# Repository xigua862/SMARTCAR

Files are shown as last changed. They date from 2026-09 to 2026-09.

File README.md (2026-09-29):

# SMARTCAR · 智能循迹小车

本分支为 **FW:0929-R1**，基于 `fw-0926-G40` 修复葫芦圈换向相关控制问题。参见[修改与试车说明](README-0929-R1.md)；可直接下载[已编译 HEX](firmware/0929-R1/test16.hex)。编译和软件回归通过，尚未实车验证；本版关闭固定里程强制右转，末端出口需另行标定。

西南石油大学校赛智能车（2026 年 10 月）—— 循迹 + 差速竞速车。
**STM32F103C8T6 + HAL 库 + Keil MDK 工程**；赛道为黑底 25mm 白线，含直角弯 / 十字 / Ω 回头弯 / 相切圆环。

---

## 硬件

| 部分 | 说明 |
|---|---|
| 主控 | STM32F103C8T6 核心板（插在自制 PCB 上） |
| 驱动 | TB6612 ×1 → 2× JGA25-370 减速电机（620rpm，差速转向） |
| 循迹 | 8 路灰度/红外模块（数字量，装在车头前伸的**可调扩展板**上，前瞻 124mm） |
| 测速 | 编码器正交解码（左 TIM3 = PA6/PA7，右 TIM4 = PB6/PB7） |
| 姿态 | MPU6050（I2C2 = PB10/PB11） |
| 底盘 | 三点式：后两轮驱动 + 前球脚轮；3D 打印底板（149.84 × 122.69 × 2.5mm） |
| 人机 | LED×3（PC13/PB14/PB15，**高电平点亮**）+ 启动键（PB9）+ 蜂鸣器（PA11，当前硬件故障） |

## 目录

```
Core/App/             ← 我们自己写的分层框架（唯一需要改的地方）
  app_config.h        ★★ 调参入口：参数 / 功能开关 / 引脚表 / 版本号
  app.c/.h            顶层调度（10ms 控制节拍 + 10ms 人机节拍 + 遥测节拍）
  telemetry.c/.h      串口遥测 + 在线调参（寄存器级中断，防 HAL 卡死）
  drivers/            motor / line_sensor / speed / encoder / led / buzzer / key / imu / odom(里程计)
  control/            pid / filter / line_follow（PD + 速度自适应 + 丢线 + 十字 + 葫芦出圈）
  fsm/car_fsm.c       状态机 IDLE→读秒→RUN→STOPPED/EMERGENCY
Core/Src  Core/Inc    CubeMX 生成的（main/gpio/tim/usart/it/msp/freertos）+ 手写 i2c.c（I2C2）
                      + FreeRTOSConfig.h（RTOS 配置）
Drivers/              ST 官方 HAL + CMSIS
Middlewares/          FreeRTOS + CMSIS-RTOS2（2026-09-23 队友引入）
MDK-ARM/              Keil 工程 test16.uvprojx
文档/                  设计文档 / 比赛规则 / 调研记录 / 代码交接说明 / **实车复盘**
机械结构/               SolidWorks 模型 + STL（底板、扩展板）
硬件设计/               PCB 工程包 + BOM
脚本/                  tune.ps1（串口调参辅助）
```

## 编译 & 烧录

1. Keil uVision5 打开 `MDK-ARM/test16.uvprojx` → `F7` 编译 → `F8` 下载
2. 命令行编译：`UV4.exe -b "MDK-ARM\test16.uvprojx" -o "MDK-ARM\build.log"`
3. 或用 OpenOCD（ST-Link，SWD：PA13/PA14）：
   ```
   openocd -f interface/stlink.cfg -c "transport select swd" -f target/stm32f1x.cfg \
           -c "adapter speed 500" -c "program MDK-ARM/test16/test16.hex verify reset exit"
   ```

## 串口命令（115200，每条必须以 `\r\n` 结尾）

| 命令 | 作用 |
|---|---|
| `P 3.0` / `D 0.5` | 设 KP / KD |
| `S 70` | 设**直道**速度（弯道自动 ×0.7） |
| `T 1 40` / `T 2 40` | 单电机测试（正数 = 前进）；`T 0 0` 停 |
| `M 40 40` | 直接给左右轮 PWM（测试模式） |
| `L 0~7` | 直接点灯（bit0=LED1） |
| `B [ms]` | 蜂鸣器响 |
| `R` | 串口启动（= 按启动键：3 秒读秒 → 跑） |
| `V` | 打印版本横幅 |
| `H` | 诊断：8 路位图 + 按键 + 编码器 + IMU（`WHO=` 应为 68） |
| `O` | 读里程：`ODOM NOW: OD=xxxxmm PATH=yyyymm L=.. R=..`（**手推标定用**） |
| `Z` | 里程清零：`OK ODOM RESET`（不用断电就能反复测） |
| `X` | **急停**（连发两个 `XX` 才生效，防噪声误触发） |

**遥测行**（待机 500ms / 运行中 50ms 一行；字段很多，常用的加粗）：
```
FW:0923-5400 IR:10110000 RPM1=210 RPM2=205 KP=3.0 SP=52 ST=2 DT=10 OD=1234 PATH=1250
ODE=0 OS=0 GZ=0 GW=0 SB=0 G7=3 GX=0 GR=0 CX=4 BR=1 GE=0 GD=0 IG=0 EH=1
```
| 字段 | 含义 |
|---|---|
| **`ST=`** | 0 待机 / 1 读秒 / 2 运行 / 3 到站 / 4 急停 |
| **`IR=`** | 8 路位图，**第 1 个字符 = 最左那一路**（权重 -7…+7） |
| `RPM1/2` | 左右轮实测转速（编码器） |
| **`DT=`** | **实测控制周期**（应稳定在 10；明显 >10 = 主循环被拖慢） |
| **`OD=` / `PATH=`** | 里程：净位移 / 走过总路程（mm） |
| **`ODE=`** | 从"进葫芦圈那一刻"起算的位移（mm）—— 出圈里程判据就看它 |
| `OS=` | 本窗口内"同一拍多次子采样位图不一致"的拍数（>0 = 过采样在起作用） |
| `GZ=` | MPU6050 偏航率（°/s） |
| `GW=` | 葫芦相切点计数（`USE_GOURD_SM`，现在主要当诊断用） |
| `SB=` | 直线提速生效中 |
| `G7/GX/GR` | 最右一路触发计数 / 已触发过出圈标志 / 硬转剩余拍数（`USE_G7_TURN=0` 时后两个恒 0） |
| **`CX=` / `BR=`** | 判成十字的次数 / "只贴一端→拒绝当十字"的次数 |
| `GE/GD/IG/EH` | 出圈状态机：进圈印记 / 印记倒计时 / 是否在圈内 / 边缘保持生效 |

## 调参入口（只在 `Core/App/app_config.h`）

> ⚠️ 这个文件现在有 780+ 行、分节带注释，**改之前先读该节顶部的说明**——里面写了每个数的来历
> （哪个是实测的、哪个是推算的、改电压要重算哪些）。以下只列分类，不重复数值。

- 开关：`USE_ENCODER` / `USE_IMU` / `USE_SPEED_LOOP` / `USE_ADAPTIVE_SPEED` / `USE_D_FILTER` / `USE_STRAIGHT_BOOST` / `AUTO_START_ENABLE`
- 十字：`CROSS_ACTIVE_MIN` / `CROSS_CONFIRM_CNT` / `CROSS_MAX_FRAMES` / `CROSS_NEED_BOTH_ENDS` / `USE_CROSS_BUDGET` + `CROSS_BUDGET_MAX` / `CROSS_REARM_FRAMES`
- **葫芦出圈**：`USE_GOURD_EXIT`（总开关）/ `USE_GOURD_EXIT_ODOM` + `GOURD_EXIT_ODOM_MM` + `GOURD_EXIT_ODOM_FROM_START`（里程判据）/ `GOURD_EXIT_USE_YAW`（偏航角闭环）/ `GOURD_EXIT_TURN_FRAMES`（拍数保险）/ `USE_GOURD_IG_GYRO`（进圈判据）
- 旧的"最右一路计数硬转"：`USE_G7_COUNT`（计数，诊断用，**保持开**）/ `USE_G7_TURN`（**当前 0 = 关**，见下方复盘）
- 红外过采样：`LINE_OS_ENABLE` / `LINE_OS_SAMPLES` / `LINE_OS_SPACING_US` / `LINE_OS_VOTE_MAJORITY`
- 边缘保持：`USE_EDGE_HOLD`；提速：`STRAIGHT_BOOST_*`
- 循迹：`KP` / `KD` / `SPEED_STRAIGHT` / `SPEED_CURVE` / `CURVE_ABS_ERR_THRESH`
- 丢线：`LOST_SPIN_DELAY` / `LOST_SPIN_SPEED` / `LOST_MAX_CYCLES`
- 里程计：`ODOM_UM_PER_COUNT`（um/计数）、`ODOM_SIGN_L/R`
- 速度闭环：`SPD_PID_KP/KI/KD/IMAX`、`RPM_PER_PWM_X100`（**改电池电压要按比例改它**）
- 极性：`LINE_ACTIVE_LEVEL`（本车 8 路模块 = **白线输出高** → `GPIO_PIN_SET`）
- 电机方向：`MOTOR_LEFT_INVERT` / `MOTOR_RIGHT_INVERT`
- 版本：`FW_TAG`（改完代码更新，**取真实时间** → 串口每行都带，一眼确认烧没烧）

## ⚠️ 踩过的坑（改代码前先看）

1. **CubeMX 重新生成后必查三处**：`usart.c` 的 USER CODE 区要保留 WordLength/StopBits/Parity/**Mode** 四行（6.17 生成时会吞掉 → 串口收发全废）；`main.c` 的 `#include "app.h"` 必须在 USER CODE 区；`.ioc` 里编码器枚举要写 `TIM_ENCODERMODE_TI12`
2. **PB10/PB11 上是 I2C2，不是 I2C1** ← 写错过。I2C 驱动是**手写**的（`Core/Src/i2c.c`），不走 CubeMX；换新工程要手动放开 `stm32f1xx_hal_conf.h` 的 `HAL_I2C_MODULE_ENABLED`
3. **`motor.c` 必须 include `app_config.h`**（否则 `#if MOTOR_LEFT_INVERT` 被当 0，方向反转静默失效；已加 `#error` 守卫）
4. **8 路模块若供 5V，DO 可能是 5V 电平** → PA0/PA1/PB0/PB1 **不耐 5V**，接线前先量
5. **烧录和串口别同时插两条 USB**（两个地回路打架 → 串口收不到）。烧录用 ST-Link、调参用串口，一次一条
6. **电池没电 = 电机嗡嗡转不动**（不是代码问题，先量 VM 电压）
7. **别往字符串字面量里写中文** → 会触发 ARMCC `#870-D`（源文件是 UTF-8，ARMCC 按 GBK 双字节规则扫）。**字面量一律用英文，注释里中文没事**
8. **CubeMX 重新生成有把工程搞坏的历史**（9/22 出过一次事故：多文件被冲）→ 生成前先 commit，生成后逐项核对，见 `文档/事故-CubeMX重新生成破坏工程-20260922.md`
9. **`speed_update()` 全工程只被 `telemetry_report()` 调用** → 以后做"静默/关遥测"的改动，**判断必须放在 `speed_update()` 之后**，否则测速冻结，"车是否真的在跑"的判据会失效
10. **`LED1 = PC13` 只在急停/停车时闪**，而那两处无条件调了 `print_odom()` → 所以 **"PC13 在闪" 等价于 "`print_odom` 执行过"**，是个现成的诊断等式

## 当前状态（2026-09-23 晚）

- 固件 **FW:0923-5400** —— **新基线 = 队友实车验证过的那条线**
  （`main` 在 `96b2940` 以它为准合并；队友自己的完整版仍在分支 `team/0923-5400` / 标签 `fw-0923-5400`）
- **电池已换 12V 锂电池**（3S：标称 11.1V / 满电 12.6V）。队友**故意取"适度提速 +20%"**（PWM ×0.74）：
  `BASE_SPEED 44` / 直道 52 / 弯道 36 / 提速 70，**`KP` 仍 3.0**（注释写"先跑一次看弯道摆不摆头，摆了再降"）。
  ⚠️ 改电压要重算的清单写在 `app_config.h` §二 顶部；注意 `RPM_PER_PWM_X100` 要 **×1.622**
- **已实现**：串口在线调参 · 编码器测速 · **里程计**（`OD`/`PATH`/`ODE`，含 `O`/`Z` 标定命令）·
  速度自适应 · 丢线兜底 · 十字形状判据（两端都贴）· **葫芦出圈 = 里程 + 偏航角闭环** ·
  **红外过采样 8 次 + 多数表决** · 边缘保持 · 直线提速 · MPU6050 偏航率 · FreeRTOS
- **★实车已验证的三条结论（别推翻）**：
  1. **图案判据驱动动作 = 死路** —— `11000000` 在左直角弯出口同样出现，`REQUIRE_ENTRY` 闸门也挡不住
  2. **开环盲走有害** —— 22 拍日志证明它会把"本来在收敛的 PD"强行关掉
  3. **出圈只能靠里程** —— 详见 `文档/真相-3800为什么过不了葫芦圈-20260923.md` 与
     `文档/失败复盘-出圈判据打坏直角弯-20260923.md`
- **待办**：终点停车（到 G 停住，规则里不到 G 停 -5 分）· 速度闭环（已实现但**暂停中**，需先把 PID 整定好）·
  蜂鸣器硬件 · 串口 RX 待实测 · `USE_CROSS_BUDGET` 的 `4` 待实测标定
- 更多细节见 `文档/给接手AI的复查提醒-20260923.md`、`文档/文档索引与状态.md`、`文档/对话记忆与交接-20260910.md`

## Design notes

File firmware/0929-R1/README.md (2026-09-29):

# FW:0929-R1

`test16.hex` 是本分支对应源码的 Keil ARMCC 5.06 update 5 构建结果，目标 STM32F103C8。SHA-256 在 `SHA256SUMS` 中；编译日志在 `MDK-ARM/build-0929-R1.log`。

本固件用于实车对照测试，尚未验证葫芦圈通过率。左右电机补偿和 G40 速度/PID 参数保留；固定累计里程强制右转默认关闭，末端出口需要另行标定。具体变化、测试步骤与回退开关见根目录 `README-0929-R1.md`。

HEX 包含编译日期和时间；重新编译产生的文件校验值可能不同。

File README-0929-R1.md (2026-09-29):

# G40 葫芦圈修正版 0929-R1

本工程以用户提供的 `SMARTCAR-工程0926-G40` 为基线，与 `SMARTCAR-FW0924-1804` 对比后制作。原工程和工作区 `SMARTCAR` 的未提交改动均保留。本版尚未上车验证，不代表已能稳定通过四个相切圆。

## 使用

- Keil 打开 `MDK-ARM/test16.uvprojx`，目标为 `test16`。
- 固件版本标记应为 `FW:0929-R1`；HEX 为 `MDK-ARM/test16/test16.hex`。
- 仓库附带本次已编译固件 `firmware/0929-R1/test16.hex`，校验值见同目录 `SHA256SUMS`；重新编译的输出仍在上述 Keil 目录。
- 命令行运行 `./build.ps1` 可重新编译，默认使用本机 `C:/keil5/UV4/UV4.exe`。
- 本次仅编译和软件回归，不自动烧录或启动电机。

## 本次修改

1. 修复转向记忆的左右不对称。原程序按差值正负选择“增长/衰减”，又逐拍截断为整数，导致正负方向响应不同。例如恒定 PD 输出为 +23/-23 时，旧算法的长期总修正约为 +23/-39。改用浮点状态，按幅值增减选择速率；方向反转时立即释放旧记忆。新算法两方向镜像对称。这里修复的是软件偏置，电机的物理差异仍由原有左右增益补偿。
2. 一两拍短暂丢线后不再强制把接下来 100ms 的误差压到 ±3。只有真正进入旋转找线后，才启用原有恢复缓冲，并清除旧的误差滤波、转向记忆和速度环历史。
3. 强制直行时同时清除误差滤波和转向记忆，避免“误差设为零但仍沿旧圆转弯”。停车与旋转找线更新真实 PWM 记录，便于区分控制行为。
4. 重新确认在圈内时清零离开计数，确保“连续普通线”确实连续，而不是跨段累加。
5. 测速先处理 16 位计数器双向回绕再取幅值；初始化使用实际计数；同毫秒调用不消耗计数；异常门限随实际时间间隔变化。保留 G40 每拍 ±150RPM 的原响应限制。速度 PID 使用实际测速周期。
6. 默认关闭累计 7600mm 后强制右转。累计轮程在多绕圈后不再对应真实出口，可能在圈中错误起转。本版用于验证自下而上的四圆穿越；末端专用右转需要另行标定。其他出口触发当前同样关闭，不能依赖本版自动完成末端右转。

## 保留的参数与边界

- 直道速度档 30，弯道档 24；KP=2.3、KD=0.92。
- 左轮效率补偿 1.11，右轮 1.00；原有 PWM 下限保留。
- 原 G40 速度 PID 算法和参数保留，没有同时进行速度环大幅重调。
- 不新增定时强制翻向、不提高弯道速度。现有进圈标志可能在普通急弯触发，故未用它新增电机输出限制。

转向记忆修复会改变普通弯道的实际转向响应，即使以上参数未变，也需要复查普通弯。它不能保证选对每个相切点的分支。配置文件保留了历史试验记录，其中“增量式天然不会饱和”等文字不成立，应以实际实现和测试为准。

两包均启用速度闭环，目标换算均为每档 5.5RPM，不能把旧版简单当成开环按 7/11 缩放。当前弯道名义基准目标为 132RPM，差速后两轮分别变化；这不是已经测得的带载速度。没有电池电压采样，本版没有宣称实现自动电压补偿或复现旧版 7V 的真实车速。

已知后续问题：测速接口仍返回转速幅值；原速度 PID 支持负轮速目标，两者在倒转时不一致。为避免本轮同时改变已正常的普通弯道驱动，本次暂未重构该路径。若日志仍显示反复反转、输出大跳变，应下一轮单独验证带方向测速、速度环抗饱和与低速控制。`speed_feedback_valid()` 提供异常反馈状态，本版正常控制尚未用它触发停车；持续零计数也无法仅靠此接口识别为断线。

## 建议的首轮上车对照

1. 使用相同电池电压、轮胎、传感器高度和发车位置，先记录原 G40 的直线与普通弯表现。
2. 烧录 R1，确认版本号；先检查直线、普通左右弯，再从固定入口测试葫芦圈。启动/暂停按键沿用原工程。
3. 连续测试至少 5 次，分别记录三个相切点的成功次数，以及失败是“留在原圆”“摆头丢线”还是“未进入相切点已丢线”。测试四圆后人工停车，避免将未标定的末端出口混入评价。
4. 保存串口 `IR`、`RPM1/2`、`PWM`、`DT` 及回放中的 `e/cor/sp/dcy/flg`。软件测试验证的是控制状态与计算，不是轮胎摩擦、实际车速或赛道通过率。
5. 若普通弯变差，先只把 `Core/App/app_config.h` 的 `USE_SYMMETRIC_CORR_TRIM` 改为 `0`，重新编译对照。此开关仅恢复旧转向记忆算法，其余修复仍保留。完整回退直接使用原 G40 工程。

## 验证

ARMCC 5 完整重编译通过：0 错误、0 警告。构建结果保存在 `MDK-ARM/build-0929-R1.log`。

- `./tests/speed/run.ps1`：9 组测速边界、5 组转向记忆测试通过，其中包括 10,000 拍随机镜像输入。
- `./tests/control/run.ps1`：直接执行实际主控制代码；丢线恢复、旋转恢复、强制直行、进圈计数、停车记录共 5 个场景，默认算法与回退算法各跑一遍，均通过。宿主 GCC 提示原代码双 `if` 同行的格式警告。

测试使用实际 C 实现与模拟输入，不是实车记录。未测试真实硬件运动、11V 满载动态或完整比赛路线。

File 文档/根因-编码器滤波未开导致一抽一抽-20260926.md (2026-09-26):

# 根因：编码器输入滤波未开 → 一抽一抽（2026-09-26）

- **现象**：小车走直线"一顿一顿往前窜"，有时车头左右摆
- **影响范围**：只在**闭环循迹**时出现；开环平顺
- **根因**：`TIM3/TIM4` 编码器输入的**数字滤波被关闭**（CubeMX 默认 `IC1Filter=0`）
- **状态**：⚠️ **本文件原来的"已修复并实测验证"是错的**，真正的修复见下方更正

---

## ⚠️⚠️ 重大更正（2026-09-26 晚）：本文件描述的修复【当时并没有生效】

### 错在哪

`IC1Filter = 0x0F` 被写在了 `tim.c` 的 **`USER CODE BEGIN TIMx_Init 1`** 段里，
但 **CubeMX 生成的那几行在它后面**，当场把它覆盖回 `0`：

```c
/* USER CODE BEGIN TIM3_Init 1 */
  sConfig.IC1Filter = 0x0F;      /* ← 写在这里 */
  sConfig.IC2Filter = 0x0F;
/* USER CODE END TIM3_Init 1 */

  sConfig.IC1Filter = 0;         /* ← CubeMX 生成的，覆盖回 0 */
  sConfig.IC2Filter = 0;
  HAL_TIM_Encoder_Init(&htim3, &sConfig);   /* ← 真正写 CCMR1 的是这里 */
```

HAL 内部（`stm32f1xx_hal_tim.c:3097`）才是真正写滤波器的地方：
`tmpccmr1 |= (sConfig->IC1Filter << 4) | (sConfig->IC2Filter << 12);`
而它读到的 `sConfig` 已经被改成 0。
**全工程没有第三处写滤波器** → **编码器从头到尾就没滤波过。**

### 怎么发现是假的（关键判据，下次直接用）

日志里出现 **`RPM2=747`**，而同一份 `speed.c` 自己写着：
10ms 窗口的物理上限 = 70 计数 ≈ **213 rpm**。
更硬的一条：**相邻两拍 28 → 747（只隔 10ms，一个跟斗 +719）** ——
双电机同时堵转都做不到。
⇒ 计数仍被污染 ⇒ 那个"修好了"是假的。

### 那当时的改善是哪来的

**全部来自 `speed.c` 的两道软件守卫**（它们挡住了部分垃圾值）。
守卫是真有效的，留着 —— 但它们是**兜底**，不是**治本**。
也就是说下面第 5 节那张"修复前/后"表，实际测的是【守卫】的效果，
不是【滤波】的效果。

### 真正的修法

1. `tim.c`：把那两行 `sConfig.IC1Filter/IC2Filter` 由 `0` 改成 `0x0F`
   （在 `HAL_TIM_Encoder_Init` **之前**，所以这次真的会写进 CCMR1）；
2. `encoder.c`：新增 `encoder_apply_input_filter()`，在 `HAL_TIM_Encoder_Start()`
   **之后**用与 HAL 相同的位操作再写一次 CCMR1 的 IC1F/IC2F（双保险，
   且不怕将来再被 CubeMX 覆盖）。

### 实测（`FW:0926-FILT`）

| | 修复前 | 修复后 |
|---|---|---|
| 最大 RPM | **747**（物理上限 213）| **426** |
| 相邻两拍最大跳变 | **+719** | ≈ ±150（受守卫限制）|
| 用户主观 | "到相切点疯狂摆头" | **"好多了"** |

### ★★ 从这件事里抽出来的通用教训 ★★

**"改了某个结构体字段"不等于"改了硬件寄存器"。**
只要那段代码后面还有生成代码/别的赋值，就要确认**最后是谁写的值**。
判定方法：**不要看赋值语句，去看最终寄存器写入点的入参**（这里就是
`HAL_TIM_Encoder_Init` 内部的 `sConfig->ICxFilter`）。

同理，**"改了以后变好了"不能证明"改的东西生效了"** ——
同一次提交里可能还有别的有效改动（本次就是 `speed.c` 的守卫）。
**要单独证明一个改动生效，必须让它的效果可被独立观测。**

---

> 下文（第 4 节代码、第 5 节数据）保留原样存档，但请以上方更正为准：
> 第 4 节①当时**不生效**，第 5 节的数据实际归因于第 4 节②。

---

## 1. 一句话根因

**电机 PWM 噪声窜进编码器 A/B 相 → 产生假计数 → 单拍计数出现跳变 →
`speed_get_rpm()` 算出垃圾值（-30000）→ 速度 PID 拿垃圾反馈 →
输出在 0↔60 之间 bang-bang → 小车一顿一顿往前窜。**

---

## 2. 怎么定位的（关键证据链）

排查绕了很多弯路，最后是靠**两个互相矛盾的事实**锁定的：

| 事实 | 数据 |
|---|---|
| 车实际走得很顺 | OD 逐拍增量稳定 **5~6mm**（56+49 次），**负增量 0 次 / 148** |
| 但测速报垃圾 | `RPM1 min=-30000 avg=-1620`、`RPM2 min=-30000 avg=-41`（**平均值为负**）|

**车从没倒退过，测速却报负值 —— 两者不可能同时为真** → 是读数被污染。

再看 PID 输出波形（轨迹里的 `PWM=`）：

```
T000 PWM= 60/60   T001 PWM=  0/60
T002 PWM= 60/60   T003 PWM=  0/60     ← 每隔一拍在 0↔60 之间跳
T004 PWM= 60/60   T005 PWM=  0/60
```

这是 **bang-bang 饱和振荡** —— 控制器拿垃圾反馈，在两个极限之间来回撞。

---

## 3. 为什么"开环平顺、闭环才抽"

| | PWM 状态 | 噪声 | 结果 |
|---|---|---|---|
| **开环**（`M 60 60` / `T 1 60`）| **恒定不调制** | 不产生 | 编码器读数干净 → 273 RPM、**波动仅 ±2%** |
| **闭环循迹** | 一直在调制 | 持续产生 | 计数被污染 → PID 暴走 → 一抽一抽 |

这也解释了排查中另一个困惑：**为什么里程（OD）正常、转速（RPM）垃圾** ——
里程用**低频累积**、测速用**单拍差分**，差分对毛刺极度敏感。

---

## 4. 修法（两处，双保险）

### ① `Core/Src/tim.c` —— 打开硬件输入滤波（治本）

`MX_TIM3_Init()` 与 `MX_TIM4_Init()` 里，**放在 `USER CODE` 段内**
（本项目有"CubeMX 重新生成破坏工程"的前车之鉴，务必保持在 USER CODE 里）：

```c
sConfig.IC1Filter = 0x0F;
sConfig.IC2Filter = 0x0F;
```

- `0x0F` = 在 `f_DTS/32` 采样率下**连续 8 次一致才认账**，可滤掉 <~4.3µs 毛刺
- 编码器最高频率约 6.5kHz（465RPM × 14 沿 → 每脉冲 154µs）
  → **绝不会误滤真实脉冲**

### ② `Core/App/drivers/speed.c` —— 可信性校验（治标，兜住漏网）

在 ±30000 钳位**之前**加两道：

```c
/* 第①道：计数跳变守卫 —— 10ms 窗口内合法上限 33，取 2 倍余量 = 70 */
if (d > 70) rpm = rpm_prev[v];          /* 跳变 → 沿用上次有效值 */

/* 第②道：变化率限制 —— 真实瞬态 ≤50rpm，取 ±150rpm 宽余量 */
限制每拍变化 ±150rpm
```

**两个特意避开的坑：**

- **不用 `if (rpm<0) rpm=0`** —— 本车有**倒转工况**（丢线后原地找线用负转速），
  一刀切会破坏它；而且 `speed.c` 无从知道车此刻的意图方向
- **不直接丢弃跳变**，而是沿用上次有效值 —— 避免反馈变陈旧导致积分饱和

---

## 5. 验证结果

同一工作点（目标 165 RPM = 30 PWM × 5.50）闭环测试：

| 指标 | 修复前 | **修复后** |
|---|---|---|
| `RPM1 min` | **-30000** | **0** ✅ |
| `RPM1 avg` | **-1620** | **+146** ✅ |
| `RPM2 avg` | **-41** | **+148** ✅ |
| `WAVE PWM` | `60 0 60 0 60 0` | `36 36 30 41 30 36…` ✅ |
| `SAT`（输出打满拍数）| lo=15 hi=36（**51/150**）| lo=3 hi=19（**22/150**）✅ |
| 稳态转速 | — | **159 RPM**（目标 165，差 3.6%）|
| 逐拍位移变异系数 | **42%** | **15%** ✅ |
| 逐拍标准差 | ±72 RPM | **±24 RPM** ✅ |

残留的 ±24 RPM 里，**±14 RPM 是编码器量化噪声**（165RPM 下 10ms 只有 ~11.6 个计数，
分辨率 14 RPM = 8%）—— 属测量分辨率极限，不是控制问题。

---

## 6. 排查中走错的路（留档，别重复走）

按时间顺序，以下怀疑**全部被实测推翻**：

| 怀疑 | 推翻它的证据 |
|---|---|
| 电机带载不给力 | 开环 @60 PWM 实测 **273 RPM、0.94 m/s、波动 ±2%** |
| 电源/电池压降 | 满功率稳定跑 3 秒无衰减 |
| 齿轮箱打滑、机械阻力 | 分段速度完全一致（284/291/294/287/277 RPM）|
| 编码器 PPR 标定错 2 倍 | 编码器算出的 273 RPM 与物理车速 0.94 m/s **完全自洽** |
| 编码器 16 位回绕 | 165RPM 下回绕周期 93 秒 > 一趟时长 |
| 积分限幅过大（IMAX 50→12、KI 0.1→0.04）| **实测更差**（右轮中位数 170→71）；已回退，失败记录存在 `app_config.h` |

**教训**：这次故障只体现在**单拍差分**上，而我一直用**平均转速**推理 ——
平均值正常，所以方向全错。**遇到"平均对、瞬时乱"要先怀疑测量链路，而不是执行机构。**

---

## 7. 顺带修的诊断基建（保留可用）

- `telemetry.c`：轨迹行加 `PWM=l/r` 字段（`T042 PWM= 36/ 35 IR:… GZ=… OD=…`）
- `line_follow.c`：`line_follow_test_stats_tick/dump()` —— **板载统计，只打 6 行**，
  不依赖人工抄 150 行轨迹（本车串口在丢字符，长回放抄不动）
- `app_config.h`：`TEST_AUTO_OPENLOOP` / `TEST_SPEEDLOOP_MODE`（0=开环 1=闭环 2=正常循迹）
- `app.c`：开机自动测试框架（**当前已关闭**，`TEST_AUTO_OPENLOOP=0`）

> ⚠️ 复测提示：把 `TEST_AUTO_OPENLOOP` 改 1 会让小车**上电就自己冲出去**，
> 测完务必改回 0。

---

## 8. 待办

- [ ] **实车跑一整趟确认**（本修复是闭环台架验证，还没跑真赛道）
- [ ] 那 17 个本地提交**仍无远端备份**；本轮改动也全部未提交
- [ ] `speed.c` 里"速度闭环当前是关的（USE_SPEED_LOOP=0）"这段注释已**过时**
      （开关早在 2026-09-23 就打开了），会误导人
- [ ] `telemetry_report()` 的注释说"行长 ~78 字符"，实际已超 80 列

---

# 附录：同期确认的另外两条硬结论（2026-09-26）

## A. 陀螺 ±2000dps 档在这颗芯片上不可用 —— **改代码修不了**

| 时间 | 做了什么 | 结果 |
|---|---|---|
| 09-24 | 写 `0x18`(FS_SEL=3, ±2000dps) | **写不进去**，芯片留在 ±250 默认档 → GZ 读数大 8 倍 |
| 09-24 | 改 `0x10`(FS_SEL=2, ±1000dps) + 读回校验 | ✅ 生效，GZ 从此正常 |
| 09-26 | 再次写 `0x18` | ❌ **`GZ` 恒为 0**（比写不进去更糟），已 `git revert` |

`0x10` 与 `0x18` 只差 FS_SEL 一个 bit（2 vs 3），前者稳定可用、后者直接坏
⇒ **这颗芯片（大概率国产 MPU6050 克隆）的 FS_SEL=3 位是坏的/未实现的。**
⇒ **±1000dps 是它能给的最宽档位**，"换更宽档位解决削顶"这条硬路已经走不通。

**该档下削顶客观存在**：`|GZ| >= 990` 占 **7.4%**（34/457），`GZ=-995` 重复 **25 次**
（反复落在同一个数 = 削顶签名；995 ≈ 32767/32.8 = ±1000 档满量程）。

**当前做法（2026-09-26）**：不再盲改档位，改为**先量清楚削顶是不是葫芦圈的瓶颈** ——
遥测短行新增 `SAT=<0|1>`（本拍是否削顶）与 `SATN=<累计次数>`：

- `SAT=1` 只集中在"打滑自旋"段、正常穿越 S 形时基本为 0
  → **削顶不是瓶颈**，别再折腾陀螺，换方向
- 穿越过程中 `SAT` 持续为 1 → 偏航积分确实少算，才值得设计软件补偿

## B. ⚠️ 工程教训：不要把"改一个全局参数"和"开一个依赖它的新功能"放进同一个提交

本次犯的错：同一个提交里既改了 `imu.c` 的陀螺量程，又打开了依赖陀螺的
`GOURD_ARC_FLIP`。结果出问题时**无法干净归因** ——
虽然从"`GZ` 恒为 0"能推出是量程，但代价是多烧一版、多跑一趟车。

**正确顺序**：先单独改量程 → 只验证"`GZ` 读数还正常吗" → 确认后再开依赖它的功能。

---

# 附录 B：葫芦圈"过不了" —— 2026-09-26 的诊断记录（**未解决**）

## ⚠️⚠️ 首先撤回一条错误结论（2026-09-26 深夜更正）

当晚我曾写下"葫芦圈首次通过、`WHEEL_PWM_FLOOR` 有效" —— **这个结论是错的，已撤回。**

**错在哪**：那趟（`FW:0926-2015`）我引用的证据是

```
GOURD-ENTRY mark set  → 一次都没出现
GW 全程 = 0
IG 全程 = 0
```

我把这三条读成了"打转消失了"的证据。**但它们真正的含义是"这一趟根本没在测葫芦圈"** ——
车**从未进入葫芦圈状态**（`IG` 从未置 1）→ 葫芦圈逻辑全程没介入 →
它只是按普通循迹走完了整段 → **没有跨过任何相切点 → 没有证明任何东西**。

用户随后反馈："**好像是偶然，不能复现**" —— 与这个更正一致。

**教训（和我当天犯的其他几次是同一个模式）**：
**先给结论、再找证据。** 证据明明摆在眼前，还是被读成了支持结论的方向。
⇒ 判据"某功能修好了"之前，必须先确认"**这个功能这一趟真的被触发过**"。

## 目前确认为真的部分

| 结论 | 状态 |
|---|---|
| 左轮"基本停转"占比 21% → 6%（`WHEEL_PWM_FLOOR` 的效果）| ✅ **可复现、数据支持** |
| 葫芦圈段里程 10872 → 8894mm | ✅ 数据支持（但那是含打转的一趟）|
| **"葫芦圈通过了"** | ❌ **撤回**：那趟 `IG` 全程 0，没测到 |
| **`WHEEL_PWM_FLOOR` 修好了葫芦圈** | ⚠️ **未证实** |

## ★ 一条待验证的关键推理：陀螺失效可能才是那趟"不打转"的原因

`IG`（进圈判据）**依赖陀螺**（`USE_GOURD_IG_GYRO=1`，判据是"10 拍内 `Σ|GZ|` ≥ 1000"）。

```
GZ 恒为 0  →  Σ|GZ| 永远 < 1000  →  IG 永远不置 1
           →  葫芦圈逻辑永不介入  →  车退回普通循迹  →  【反而没打转】
```

⇒ **那趟"顺利走完"很可能是"陀螺坏了 → 进圈判据失效"造成的假成功。**
⇒ 反过来推：**正常跑时（陀螺有效）车会进圈 → 葫芦圈逻辑介入 → 打转。**

**如果这条成立，问题可能出在"葫芦圈逻辑介入本身"，而不是左轮。**

⚠️ 但这只是推理，**未验证**。下一步必须先确认：**陀螺到底是稳定有效还是间歇失效**。
判据：连跑几趟，看 `GZ` 是否始终随转向变化；若某趟恒为 0，即为间歇失效。

## 为葫芦圈试过的 5 条路线（全部失败）

| # | 路线 | 结果 |
|---|---|---|
| ① | 相切点直行窗口（历史 9-24）| ✗ 更差 |
| ② | GW 计数触发（历史 9-24）| ✗ |
| ③ | 直行窗口 + `CROSS_ACTIVE_MAX` 宽度上限 | ✗ 触发 13→20 次（上限只堵了 r.raw 一路，1kHz 那帧总能找到更宽的帧）|
| ④ | 陀螺偏航积分 `GOURD_ARC_FLIP` | ✗ 因我改坏陀螺而中断，未真正验证 |
| ⑤ | 葫芦圈后半段减速 `USE_GOURD_SLOWDOWN` | ✗ **"疯狂摇头"**（见下）|
| ⑥ | `WHEEL_PWM_FLOOR = 12` | ⚠️ 左轮停转确实改善（可复现），但**与葫芦圈的关系未证实** |

## 路线⑤失败的机理（这条是确凿的，值得记）

弯道基准 `sp = SPEED_CURVE = 24`，减速 65% → `sp = 16`。
参与差速的那一轮 = `sp ∓ corr`（`KP=2.0`）：

```
e=3 → 10    e=5 → 6    e=8 → 0
```

而刚加的 `WHEEL_PWM_FLOOR = 12` 会把 **8~11 这一段抬到 12**：

```
控制器本想要 8~11 → 实际给 12；下一拍还是要 8~11 → 又给 12 ……
→ 该轮被持续抬着走 → 转向不足 → 车往切线方向冲 → e 变大 → 修正更猛
→ 一冲一拽 = "疯狂摇头"
```

**教训：两个都在"补左轮/救弯道"的机制，叠加时会互相打架。**
各自单独看都对，合起来错。加这类补偿前要先把两者的**工作区间**算清楚。

## 依然存在的独立问题

| 问题 | 状态 |
|---|---|
| **陀螺间歇性失效**（见附录 C）| ⚠️ **未解决，且可能是葫芦圈问题的关键** |
| 出圈右转（4 个触发全关）| ⏸ 用户要求先放着 |
| 串口丢字符 | ⏸ 未处理 |

---

# 附录 C：陀螺【间歇性】失效（2026-09-26，与量程改动无关）

## 现象

| 固件 | `GZ` 表现 | 备注 |
|---|---|---|
| `0926-1900` | 正常（峰值 556，随转向变化）| |
| `0926-1920` | 正常（-7 ~ 322）| |
| `0926-1830` | **恒为 0** | 当时我改了量程 → 曾误判为量程问题 |
| `0926-2015` | **恒为 0** | ⚠️ **量程已 revert 回 0x10，代码与 1920 同源** |

**⇒ 量程已回退、代码同源，`GZ` 却又恒为 0。**
**⇒ 陀螺是【间歇性失效】，不是量程改动引起的 —— 是硬件/接线层面。**

## 影响

- `GOURD_ARC_FLIP`（偏航积分换向）**不可用** —— 它依赖陀螺
- `USE_GOURD_IG_GYRO`（进圈判据）**不可靠** —— 本次 `IG` 全程为 0 可能就是它
- `USE_YAW`（出圈角度闭环）**不可靠**
- ✅ 但**不影响当前已通过的葫芦圈**：本次 `IG` 全程 0 却仍走通，
  说明现在这条路线**不依赖陀螺**

## 想用回陀螺功能前必须先解决

排查方向（按可能性）：
1. **I2C 接线**：MPU6050 是 I2C2（PB10=SCL / PB11=SDA）—— 接触不良、杜邦线松动
2. **供电**：模块 3.3V/5V 供电是否稳定（电机一启动就掉压 → I2C 失败）
3. **`imu_read_raw()` 的静默失败**：I2C 读失败时它**提前 return、全局量保持不动**，
   而 `imu_update()` **不检查返回码** → 读失败时 `gz` 保持旧值。
   ⚠️ 若上次读到的恰好是 0，就会一直显示 0 —— **这是软件放大的地方**，
   可以加"连续读失败计数"暴露出来（但根因在 1/2）

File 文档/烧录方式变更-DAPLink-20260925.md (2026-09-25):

# 烧录方式变更：ST-Link → CMSIS-DAP（DAPLink）

- **生效日期**: 2026-09-25
- **原因**: 原来的 ST-Link（SN 尾号 `ECCE1A43`）换掉了，改成 CMSIS-DAP / DAPLink

---

## 1. 变更前后对比（很重要，旧笔记已失效）

| | 旧（ST-Link） | 新（CMSIS-DAP / DAPLink） |
|---|---|---|
| 硬件 | ST-Link V2，SN `37FF71064E573436ECCE1A43` | CMSIS-DAP 下载器，SN `1582521132` |
| 烧录命令 | `ST-LINK_CLI.exe -c SWD UR -P x.hex -V -Rst` | `UV4.exe -f x.uvprojx` |
| 回读命令 | `ST-LINK_CLI.exe -r8 0x08002000 0x3FFF` | **没有了** ✗ |
| 逐字节校验 | `_work/verify_build.js` 比对设备 vs hex | **做不了** ✗ |

## 2. 现在的工作流

```powershell
# 编译
& "C:\keil5\UV4\UV4.exe" -r "<repo>\MDK-ARM\test16.uvprojx" -j0 -o "$env:TEMP\x.log"
# 期望: 0 Error(s), 0 Warning(s)，exit=0

# 烧录（会先编译再下载）
& "C:\keil5\UV4\UV4.exe" -f "<repo>\MDK-ARM\test16.uvprojx" -j0 -o "$env:TEMP\flash.log"
# 期望日志: Load "test16\test16.axf" / Erase Done. / Programming Done. / Verify OK.
```

## 3. 版本验证方式（因为回读没了）

1. **Keil 的 `Verify OK`** —— 下载后自动比对 FLASH 与 axf ✓
2. **固件自报的 `FW:` 标签** —— 串口第一行，最硬 ✓
   （改代码时务必同步更新 `app_config.h` 的 `FW_TAG` ✓）

## 4. Keil 里的设置（已保存，别再动）

存在 `MDK-ARM\test16.uvoptx`：

```xml
<pMon>BIN\CMSIS_AGDI.dll</pMon>          ← 调试器 = CMSIS-DAP
<TargetDriverDllRegistry>
  <SetRegEntry><Key>UL2CM3</Key>         ← 旧的 ULINK 配置（留着无害）
  <SetRegEntry><Key>ST-LINKIII-KEIL_SWO</Key>  ← 旧的 ST-Link 配置（留着无害）
  <SetRegEntry><Key>CMSIS_AGDI</Key>     ← ★新增，Keil 自动生成
```

## 5. ⚠️ 一个必须记住的坑

商家给的配置图是 **STM32F407VGT6** 的，本工程是 **STM32F103C8**：

- **Debug 页**的设置跟芯片无关，可以照抄 ✓
- **`Flash Download` 页的下载算法千万别照抄** ✗
  本工程必须是 **`STM32F10x_128`**（`STM32F10x_128.FLM`）✓

## 6. 踩过的弯路（省得再走）

- 改 `.uvprojx` 的 `<TargetDllName>` → 报 `BIN\BIN\... not found` 或 `invalid debug Dll` ✗
  （那里只是 AGDI 内核，**调试器的选择在 `.uvoptx` 的 `<pMon>`**）
- 只改 `<pMon>` 不补 `<TargetDriverDllRegistry>` → 报 `Internal DLL Error` ✗
- 手改 `.uvoptx` 半天，不如 **GUI 里点一次 OK** —— Keil 会自动把 `<pMon>` 和 `<Key>` 都写对 ✓✓✓

## 7. 沙箱限制（环境相关）

- 工作区路径含中文 → spawn 的 python 收到乱码路径，venv 建不起来 ✗
  （所以没走 pyOCD 路线；真要用，得把环境建在纯英文路径下）

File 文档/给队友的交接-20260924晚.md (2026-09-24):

# 给队友的交接 · 2026-09-24 晚（AI 代笔，一次性把现状讲全）

> 一句话：**车能正常跑直线/弯道了；葫芦出圈还没接通**（判据在实测中，触发全关着）。
> 当前固件 **`FW:0924-2005`**，`main` = `b74a47d`，标签 `fw-0924-2005`，全部已 push。
> 先读这份 → 再读 `文档/复查-出口触发冗余盘点-20260924.md` 与 `文档/给接手AI的复查提醒-20260923.md`。

---

## 一、怎么编译 / 怎么烧 / 怎么看数据（照抄就行）

```bash
# 编译（Keil 命令行，约 3 秒）
powershell -File _tmp/build.ps1          # 期望：0 Error 0 Warning  ← 这是本项目的验收线

# 烧录（ST-Link，SWD）
openocd -f interface/stlink.cfg -c "transport select swd" -f target/stm32f1x.cfg \
        -c "adapter speed 1000" -c "program MDK-ARM/test16/test16.hex verify reset exit"
```

**⚠️ 一次只插一条 USB**：烧录插 ST-Link、读串口插 CH340 —— 两条同时插会因地环路把串口搞死（本项目实测过）。

**读/发串口的小工具**（都在 `_tmp/`，纯 ASCII 脚本，自动找 CH340 端口）：
- `readcom.ps1` —— 读 3 秒遥测
- `sendcmd.ps1 "命令"` —— 发一条命令并读回执
- `t2.ps1` —— 发 `TEST 2` 并把轨迹回放抓全
- `rpm_sweep2.ps1` —— 空载 RPM↔PWM 扫描（标定速度用）

---

## 二、车上现在是什么状态（`FW:0924-2005`）

| 项 | 值 | 备注 |
|---|---|---|
| 速度 | 直道 **43** / 弯道 **30**（≈0.82/0.57 m/s） | 12V 锂电；**直道提速已关**（它会让车在蛇形弯乱冲） |
| KP / KD | **3.0 / 1.2** | |
| 速度闭环 | **开**（含前馈） | 反馈已修成 100Hz（原先只在遥测拍更新=20Hz） |
| 起步盲直行 | **开 1000ms** | 越过起点斑马线，防被搞昏 |
| 陀螺 | **量纲已修** | 原先 GZ 放大 8 倍（读 1520~1990，实际只 ±250） |
| **葫芦出圈触发** | **全关** | 图案/里程/丢线三个都是 0 → **圈内绕圈出不去是正常的** |
| `GW`（相切点计数） | 只计数、不动作 | 新判据见下 |

**串口命令**：`P/S/D`（调参）· `T/M`（电机测试）· `L`（点灯）· `B`（蜂鸣）· `R`（启动）· `V`（版本）·
`H`（**完整长行**，含 GW/CX/BR/IG/GE…）· `O/Z`（读/清里程）· `Q`（回放轨迹）· **`TEST <秒>`**（只循迹 n 秒 + 自动回放轨迹）· `XX`（急停）

**默认遥测是短行**（约 67 字符，不折行）：`FW: ST= IR: RPM1= RPM2= OD= GZ= K1=`
`K1` = 这一窗口里 100Hz 漏看了几个 1ms 采样（**>0 就说明有东西一闪而过**）。

---

## 三、葫芦出圈：现状、判据、下一步（最重要）

**现状**：三个出圈触发全关 → 车绕圈正常但**出不去**。判据我们在用实测数据一步步定。

**已实测的特征**（数据在 `_tmp/test2.txt`，工具 `t2.ps1`）：

| | 葫芦相切点 | 直角弯 |
|---|---|---|
| 宽图案(≥5路)只贴一端 | 命中 | **也命中**（单靠它不够） |
| GZ 翻号 | **8 拍内翻**（−192→+200） | 宽图案时同号；翻号在 ~450ms 后 |
| 全灭(丢线) | **一次都没有** | **有，约 330ms** |

**当前判据（三条同时满足才算 1 个相切点）**：宽+只贴一端 **且** GZ±8拍内翻号 **且** 事件后 6 拍内无全灭。

**⚠️ 未过的问题（实测）**：
- 在**直角弯**误报过 1 次（"全灭后重新找到线"那一下也满足三条）；另一次同位置又是 0 → **不稳定**。
- `IG`（"在圈内"）**乱跳**：遥测出现 `WHO=70 / IMU=0`（MPU6050 的 WHO_AM_I 读挂了）→ 零偏标定被跳过 → GZ 带零偏 → 翻号判据容易被子噪声满足。

**下一步（已经定好，照做即可）**：
1. **修 IMU `present`**：WHO 读失败要重试（或"GZ 能读到合理变化就算在"）—— 前置项；
2. **`GW` 只在 `IG=1` 时累计；`IG=0` 强制清零** ← 这样直角弯（圈外）误报出门即清，**不依赖"误报是否稳定"**；
3. **`GW` 归 0（= 第 3 个相切点）→ 强制右转**；`GOURD_EXIT_TURN_DEG` **50 → 85**（陀螺准了，50° 是真 50°，出口要 ~90°）；
4. 各测一遍：**葫芦里 `GW` 应 1→2→0、直角弯必须一直是 0**。

---

## 四、这个项目踩过的坑（改代码前先看，都是血换的）

1. **改完立刻编译** —— 今晚我就漏了一个注释 `*/`，直接把编译搞挂；
2. **`#if` 范围必须一致**（声明/复位/使用同进同出），否则"只写不读"告警或编译不过；
3. **别信"编译通过 = 功能进去了"** —— 用 Code 体积或字符串核对（例：闭环开起来 Code +500B）；
4. **字符串字面量别写中文**（ARMCC `#870-D`，按 GBK 扫）；注释里中文没事；
5. **测试脚本发 `M`/`T` 会进测试模式**，退出要 `S`/`T 0 0`/`R`/`XX` —— **`T 0 0` 不是"停"，它会恢复循迹**；要停就 `XX`；
6. **上电时车要静止**（陀螺零偏开机标定）；
7. 急停（长按 1 秒）后要**按住启动键 2 秒**才回待机；急停时**会自动回放最近 6 秒轨迹**（不用串口）。

---

## 五、还没做的（别漏）

- **终点停车**（到 G 停；规则里不到 G 停 -5 分）—— `car_fsm_finish()` 的壳已就绪，缺触发判据（`car_fsm.c` 里的 `TODO(终点)`）；
- 蜂鸣器（硬件问题，芯片侧已验证输出正常）；
- `USE_SPEED_LOOP` 的 PID 还没整定（架空 `S 40` → 两轮应稳在 ≈220 RPM）。

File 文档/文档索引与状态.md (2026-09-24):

# 文档索引与状态（2026-09-21 更新）

> **用途**：一眼看清"哪个文件说了算、哪些是历史、哪些数据已作废"，防止被旧信息误导。
> **新对话开场**：先读本文件 → 再读 `文档/对话记忆与交接-20260910.md`。
> 🔴 **★2026-09-23 新增，接手改代码前必读**：`文档/给接手AI的复查提醒-20260923.md`
> 　（内容：你已完成的 P0 清单确认 + **3 个待处理风险** + 未完成项 + 决策优先级顺序。**先读它再动 `line_follow.c`**。）
> 🟠 **★2026-09-24 新增，建议优先处理**：`文档/复查-出口触发冗余盘点-20260924.md`
> 　（**出口触发现在有两套机制并行开着**（G7 硬转 + 出圈状态机）→ 竞态；一堆默认关闭的备选判据；
> 　`GOURD_EXIT_TURN_DEG 50°` 与遥测注释"GD 应≈90°"自相矛盾。附**四轮单变量验证方案**，
> 　判据："关掉它、功能没变差 = 它多余"。）
> **★2026-09-21 目录重整**：根目录只留 `test16.ioc`（CubeMX 必须），其余分入 `文档/`、`机械结构/`、`硬件设计/`。

> 🔴 **★2026-09-23 晚：基线变更（接手 AI 记录）**
> `main` 已**以队友实车验证过的版本 `FW:0923-5400` 为准**（合并提交 `96b2940`）。
> 队友 git 账号没注册、推不上来，是 QQ 传的包，已导入本仓库保存：
> 分支 `team/0923-5400` / 标签 `fw-0923-5400`（队友完整版，可 diff 对照）。
> ⚠️ 我先前那条按推导做的 12V 版（`FW:0923-1917`，速度 ×0.617 + KP→2.0）**已被取代**，
> 队友用的是**故意"适度提速 +20%"（×0.74）且暂不动 KP**，以他们为准；旧版仍在标签 `fw-0923-1917`。

> 🔴 **★2026-09-23 晚新增 5 篇实车复盘（权威，改葫芦/出圈逻辑前必读）**
> - `文档/真相-3800为什么过不了葫芦圈-20260923.md`
> - `文档/失败复盘-出圈判据打坏直角弯-20260923.md`
> - `文档/实车日志证据-开环为何有害-20260923.md`
> - `文档/红外过采样-20260923.md`
> - `文档/事故-CubeMX重新生成破坏工程-20260922.md`

---

## 一、当前有效（权威源）

| 文件（新路径） | 管什么 |
|---|---|
| `文档/对话记忆与交接-20260910.md` | ★★**交接总入口**（新对话先读这个）|
| `文档/新底板-车板数据-20260921.md` | ★★**新车 v2 底板关键尺寸清单**（板长/宽/孔距/球脚轮/扩展板）|
| `文档/前瞻档位对照表-20260921.md` | ★★前瞻档位 vs 内切量 + 测试记录表 + KP 系数 |
| `文档/下一版车型-尺寸建议.md` | 新车型调研结论（前瞻/轴距/轮距/总长推荐值）|
| `文档/别人的比赛车-调研记录.md` | 实车案例（10 个）+ 低趴/IMU/车长的判断依据 |
| `文档/代码方案-20260920.md` | ★代码方案（功能清单 / 框架 / M1~M7 里程碑）|
| `文档/新车设计书.md` | 电气 / PCB / 电源 / 引脚 / 人机 / BOM |
| `文档/底板布局草案.md` | 旧（复刻版）结构尺寸权威源 —— **只对旧车有效** |
| `文档/采购清单-淘宝搜索词.md` | 下单清单 + 加购进度 |
| `文档/动手前考虑清单.md` | 每次动手前的把关清单 |
| `文档/学习计划-SolidWorks.md` | SW 2025 学习路线与练习清单 |
| `文档/接线对照表.html` | 接线对照（已同步新车）|
| `文档/引脚核对与风险-20260915.md` | 引脚核对 |
| `文档/校赛智能车-重制版.md` | 校赛计划 |
| `文档/5.机器车循迹比赛规则.pdf` | **★比赛规则** |
| `文档/CSDN-B6-PID调参实战.md` | CSDN 文章草稿 |
| `文档/8路巡线模块的使用方法.pdf` | 8 路模块资料 |
| `文档/开发进度与交接.md` | ⚠️ **历史文档**（旧车开发史/踩坑/CSDN 计划）|
| `机械结构/零件2.SLDPRT` + `零件2.STL` | ★★**新车底板**（3D 打印，已装车）|
| `机械结构/零件2拓展板.STL` | ★★传感器**扩展板**（可调前瞻）|
| `机械结构/零件1.SLDPRT` | 旧（复刻版）底板模型 |
| `机械结构/新底板-草案.dxf` / `.svg` | 我出的草图（占位孔位，**已被零件2取代**）|
| `硬件设计/寻迹小车板子V3_PCB1_*.zip` | 嘉立创 PCB 工程包 |
| `硬件设计/BOM_Board1_Schematic2_2026-09-16.xlsx` | 立创 BOM 导出（板上有哪些件）|
| `Core/` `Drivers/` `MDK-ARM/` `test16.ioc` `.mxproject` | STM32 工程骨架（**勿动**）|

---

## 二、历史归档（`归档-20260918/`，别当现状用）

| 内容 | 说明 |
|---|---|
| `文档-旧车/画板手册.md`、`文档-旧车/循迹小车使用手册.md` | **旧车（test16）**资料，已随车出售 |
| `临时脚本与截图/` | 一次性自动化脚本（截图/批处理）与截图 |

---

## 三、⚠️ 已作废的旧数据（**别再引用**）

| 旧值 | 现状 |
|---|---|
| 传感中心距驱动轴 **5.0cm** → 实测 **213mm** | ❌→ **新车 v2 是 124mm**（板本体+扩展板）|
| 前支撑 = 麦轮 0° | ❌ 改 **球脚轮（牛眼轮）** |
| 轴距 8.5cm / 轮距 11.7cm / 板长 18.5 / 板宽 75-135-157 | ❌ 我们自算方案作废 → 旧车为"1:1 复刻学长的车" |
| PCB 7×10cm | ❌ 实际 **9×7cm（90×70）**，4 孔距 **83×62**（±41.5/±31）✓ STL 已核实 |
| "传感器贴近驱动轴 5~10cm" | ❌ 该经验只适用"传感在两轮之间"车型 |
| 旧车总长 229 / 前瞻 213 / 球脚轮距 182 | ❌ **新车 v2 全部重画** |

---

## 四、★新车 v2 关键参数（2026-09-21）

| 项 | 值 | 来源 |
|---|---|---|
| 板长 × 宽 × 厚 | **149.84 × 122.69 × 2.50 mm** | 零件2.STL 解析（我）|
| 传感 → 驱动轴 | **124 mm**（板本体+扩展板，最短档） | 他实测 |
| 球脚轮触地 → 驱动轴 | **79.82 mm** | 他 SW 模型 |
| 球脚轮法兰孔 | 2×φ3.2，间距 **42.3 mm** | 零件2.STL 解析 |
| 电机支架孔 | **17×17mm 四角**（两处，孔 φ3.5；中心相距 89mm） | 零件2.STL 解析 |
| PCB 安装 | 可调长槽梯子；外列间距 **85mm**（≈PCB 83） | 零件2.STL 解析 |
| 扩展板 | **72 × 40.12 × 2.0mm**，固定槽距 **65.4mm** | 零件2拓展板.STL 解析 |
| 电池 | 64 × 35（**横放**压轴，塞两电机之间） | 设计 |
| 固件 | **FW:0921-2135**（KP=3.0 / KD=0 / 直道60 / 弯道42） | 已烧录 |

---

## 五、⏳ 仍待实测

- **轮距**（两后轮中心距）——从支架孔中心 89mm 推约 106mm，待确认
- **球脚轮静载**（判据：1kg 车 = 100~150g，秤顶前支撑）
- **传感器离地**（目标 6~7mm）
- 整车称重（用于替换重心估算）

---

## 六、空间与杂物提示

- `参考库/TC264_Library-master.zip`（155MB）与解压文件夹重复 → 不需要可删
- `_tmp/` 是我的临时工作目录（脚本/备份），用完会清

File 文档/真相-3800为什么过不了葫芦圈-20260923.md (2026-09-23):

# 真相：3500 / 3800 / 4000 三个版本**都过不了**葫芦圈

日期：2026-09-23
结论来源：**逐字节 diff**（`Compare-Object`），不是推测。

> **⚠️ 接手 AI 补注（2026-09-23 晚，已核对代码）**：本文 **§七 的"定稿 403mm / 从进圈起算"只对 `FW:0923-4800` 成立**。
> 后续 `FW:0923-5400` 已改成
> `USE_GOURD_EXIT_ODOM 1` + **`GOURD_EXIT_ODOM_MM 24847`（约 24.8m）+ `GOURD_EXIT_ODOM_FROM_START 1`（从发车线起算）**，
> 并加了 `GOURD_EXIT_USE_YAW 1`（偏航角闭环）。
> **以代码为准 —— 别照本文的 403 去改 `app_config.h`。**

---

## 一、先说结论

**"3500 能过葫芦圈"这个记忆是错的。**

3500、3800、4000 这一串版本的**葫芦圈出圈代码压根没有编译进固件**：

```
#define USE_GOURD_EXIT       0      ← 整个出圈状态机被 #if 掉
#define USE_GOURD_IG_GYRO    0      ← 连"有没有进圈"都判断不了
```

所以车进了葫芦圈以后，**没有任何逻辑会让它右转出来**，
它只会顺着线一直跑 —— 也就是用户描述的：

> **"会一直绕着一个圈走"**

---

## 二、证据链（三条独立证据，互相印证）

### 证据 1：逐字节 diff —— `line_follow.c` 完全相同

```
[DIFF 2]  Core\App\app_config.h
[DIFF 3]  Core\App\app.c
[DIFF 7]  Core\App\telemetry.c
[SAME    ] Core\App\control\line_follow.c      ← ★ 控制逻辑逐字节相同
[SAME    ] Core\App\control\line_follow.h
[DIFF 33] Core\App\fsm\car_fsm.c
[DIFF 5]  MDK-ARM\test16.uvprojx
```

`app_config.h` 的那 2 行差异是**唯一一处**，内容是：

```
FW_TAG "0923-3800"  →  FW_TAG "0923-4000"     ← 就改了版本号字符串
```

**所有葫芦圈开关，3800 和 4000 完全一致。**
其余文件差异全部是里程计新增的（`odom` 调用、`OD=`/`PATH=` 遥测、`odom.c` 入工程）。

### 证据 2：`Code` 体积

| 版本 | Code | 葫芦圈状态机 |
|---|---|---|
| 3500 | 20136 | **不在**（`#if 0`） |
| 3800 | 20136 | **不在**（= 3500，checksum `0x001F7AA9` 相同） |
| 4000 | 20780 | **不在**（= 3800 + 里程计 644 字节） |
| **4100** | **23720** | **在**（开关打开，+2940 字节） |

整套出圈状态机（进圈判据 + 滑动窗口 + 三级转动判据 + 锁存 + 闸门）
的机器码大约 **2.9KB**。
3500/3800/4000 的 Code 都**没有**这 2.9KB → 代码确实不在里面。
这是"开关真的没生效"的**客观物理证据**，不依赖任何人的记忆。

### 证据 3：用户实测现象

> "现在葫芦圈过不去了" → 追问后："**会一直绕着一个圈走**"

这正是"没有任何出圈逻辑"的**必然表现**。

---

## 三、那到底是哪一版能出圈？

能出圈的只可能是**把开关打开的版本**，即 3600 / 3700 / **3900**：

| 版本 | `USE_GOURD_EXIT` | `USE_GOURD_IG_GYRO` | 葫芦圈 | 直角弯 |
|---|---|---|---|---|
| 3500 | 0 | 0 | ✗ 一直转圈 | ✓ 正常 |
| 3800 | 0 | 0 | ✗ 一直转圈 | ✓ 正常 |
| 3900 | **1** | **1** | ✓ **能出圈** | ✗ **转向反了** |
| 4000 | 0 | 0 | ✗ 一直转圈 | ✓ 正常 |
| **4100** | **1** | **1** | 目标：能出圈 | 待观察（有已知风险） |

3900 的两个现象是**同一个原因**的两面：
出圈判据 `11000000`（只有最左两路亮）
**在右直角弯的出口也会出现**（车左转时线滑向右侧），
于是直角弯被误判成"葫芦出口" → 触发 90° 硬右转 → 转向反了。

> 详见 `文档\失败复盘-出圈判据打坏直角弯-20260923.md`

**结论：出圈能力和直角弯误触发，都是 `USE_GOURD_EXIT=1` 带来的。
要"能出圈"就必须接受这个风险；要"没有风险"就只能一直转圈。
唯一的出路是把出圈判据换成不会误伤的 —— 也就是里程。**

---

## 四、由此得出的正确路线

用户方案（原话）：

> "利用编码器计数，计算小车跑了多少距离，最后到出葫芦圈的时候强制右转"

为什么里程是**唯一**不会误伤的判据：

| 判据 | 会不会在右直角弯误触发 | 原因 |
|---|---|---|
| 图案 `11000000` | **会** | 右直角弯出口图案完全一样 |
| 圈内持续丢线 | **会** | `ge_in_gourd` 印记没清干净时就误触发 |
| **按里程** | **不会** | 是**物理量**，与"看到了什么图案"完全无关 |

### 分两步走

**第 1 步（当前，FW:0923-4100）—— 恢复出圈能力 + 采集里程数据**

```
USE_GOURD_EXIT        1     ← 恢复
USE_GOURD_IG_GYRO     1     ← 恢复
GOURD_EXIT_USE_PATTERN 1    ← 用能出圈的判据先把圈过去
GOURD_EXIT_ON_LOST    0     ← 关掉（它是误触发直角弯的嫌疑之一）
USE_GOURD_EXIT_ODOM   0     ← 里程判据代码已编译在内，但先关闭
```

新增遥测 `ODE=` = **从进圈那一刻起算**的净位移(mm)。
出圈事件行也会打印：

```
GOURD-EXIT: trig=1 -> turn RIGHT   ODE=xxxxmm  (left2 lit, yaw closed loop)
```

**把那个 `xxxx` 记下来 = 葫芦圈"进圈→出口"的真实里程。**

**第 2 步（FW:0923-4200）—— 换成纯里程触发**

```
GOURD_EXIT_ODOM_MM    <上一步实测的 xxxx，建议再减 50~100mm 留余量>
GOURD_EXIT_USE_PATTERN 0    ← 关掉误触发源
USE_GOURD_EXIT_ODOM   1     ← 打开
```

从此出圈由**里程**决定 → **右直角弯不可能再被误伤**。

---

## 五、为什么里程要以"进圈那一刻"为 0 点

不是从发车算起。原因：

* 发车位置前后摆 10cm，从发车算的里程就整体偏 100mm → 每次都要重标；
* 以"进圈那一刻"（`ge_in_gourd` 0→1 边沿）为 0 点 →**与从哪儿发车无关**，
  换发车位置、换赛道摆放都不用重标。

实现：进圈边沿处记 `ge_odom_entry = odom_distance_mm();`，
之后判 `odom_distance_mm() - ge_odom_entry >= GOURD_EXIT_ODOM_MM`。

---

## 五点五、实车结果：图案判据已被证伪（FW:0923-4100，2026-09-23）

### 实测结果

| 项目 | 结果 |
|---|---|
| 葫芦圈 | **仍然出不去** ❌ |
| 右直角弯 | **又被误触发** ❌ |

### 这两件事合起来说明了什么

图案判据开着、闸门也开着，葫芦圈**却仍然出不去** ——
说明 `11000000` 在葫芦圈里命中的**不是出口，而是中途某个拐点**。

后果是致命的，因为 `GOURD_EXIT_ONE_SHOT 1`：

```
车在葫芦圈【中途拐点】命中图案
   → 转一次
   → ge_fired = 1  【上锁】
   → 到真正的出口时锁还没解 → 再也不转了
```

而且那一次中途的硬右转本身就把蛇行路线打乱了 ——
这正是最初那句"绕圈的顺序也变了，差点都没过去"的真正原因。

### 直角弯为什么连闸门都挡不住

闸门 `GOURD_EXIT_REQUIRE_ENTRY` 的前提是 `ge_in_gourd = 1`。
而进圈判据（`USE_GOURD_IG_GYRO`）是"10 拍内 |GZ| 累计 ≥ 1000 且车在跑"。

> **一个 90° 直角弯本身就是"持续大角速度"** ——
> 所以车一进直角弯，闸门立刻被打开。

**出圈能力和直角弯误触发，是同一个判据的两个后果。**

### 结论

| 判据 | 状态 |
|---|---|
| ① 图案 `11000000` | ☠ **彻底放弃** —— 直角弯和圈内拐点都误触发 |
| ② 圈内持续丢线 | ⚠ 依赖 `ge_in_gourd`，同样被直角弯打开 → 不可靠 |
| ③ **按里程** | ✅ **唯一出路**（且见下面这条有利性质） |

### ★ 里程判据有一个意外的好性质

里程判据要求 `ge_in_gourd` **连续保持**约 2000mm。
而直角弯里印记 **200ms 后就自动清了**
（线变回普通线 20 拍 → `GOURD_ENTRY_CLEAR_FRAMES`）。

> **直角弯根本撑不到 2000mm。**
> 只有真正的葫芦圈（蛇行持续转弯）才撑得住。

**所以里程判据对直角弯是天生免疫的 —— 连 `ge_in_gourd` 偶尔乱跳都不怕。**

### 里程数怎么测（不需要任何出圈逻辑能工作）

葫芦圈里车只会打转，**永远到不了出口**，所以不能靠"开到出口"来测。
改用**手推标定**（FW:0923-4200 为此加了 `O` / `Z` 两条串口命令）：

```
1. 把车放在葫芦圈【入口】，车轮贴地
2. 串口发 Z          → OK ODOM RESET (OD=0 PATH=0)
3. 用手把车沿着【预定的蛇行走线】推到"该开始右转 90°"的那个点
4. 串口发 O          → ODOM NOW: OD=xxxxmm PATH=yyyymm L=.. R=..
5. 抄下 xxxx
```

* `Z` 可以在任意位置重新清零 → **可以反复测，不用断电**
* **重复 3 次**，若三次差值在 ±50mm 内，说明可信
* 顺手看 `L=` 和 `R=`：两者差得太多说明推的时候有拖拽，数不可信
* ⚠️ 推的时候让轮子**滚动**，不要拖着走

---

## 六、里程计本身的标定（可选，不影响出圈能否成功）
`ODOM_UM_PER_COUNT = 491`（= π × 66mm × 1000 / 422 计数）。
若轮径不是实测的 66mm，`ODE` 会整体成比例偏差。

**标定方法**：直线上量好 **2.0 m**，把车放在起点，
按暂停 → 读 `ODOM STOP: OD=?mm`。应该是 2000 左右。
若不是，把 `ODOM_UM_PER_COUNT` 按 `491 × (2000 ÷ 实测值)` 修正。

> ✅ **这一步不做，出圈照样能成功。**
> 因为"测量"和"触发"用的是**同一个里程计**：
> 设真实系数错了 k 倍，测出来的阈值也跟着错 k 倍，
> 触发时再乘同一个 k → **误差自己抵消**。
> 标定只影响 `OD=` 显示的数值是不是真毫米，不影响能不能出圈。

---

## 七、结局（2026-09-23）：里程触发 **403mm** 定稿

### 实测数据

> **葫芦圈"进圈 → 出口"净位移 = 403mm**

来源：`FW:0923-4600`（里程流模式，10Hz 只发 `OD=xxxxmm`）实车读数。

> 📌 **更正上面第五节的一个估计值**：那里写的"约 2000mm"当时只是占位猜测。
> 实测是 **403mm**。免疫性结论**依然成立** ——
> 直角弯的印记只能撑约 200ms（≈60mm），**远不到 403mm**。

### 定稿版本 `FW:0923-4800`

**基底 = `FW:0923-4200`**（用户确认"这个版本没问题了"的那一版，直角弯正常），
在它之上**只叠加一处功能改动**：

```
USE_GOURD_EXIT_ODOM        0 -> 1       启用里程触发
GOURD_EXIT_ODOM_MM      2500 -> 403     实测值
GOURD_EXIT_ODOM_FROM_START  新增 = 0    从"进圈那一刻"起算
FW_TAG          "0923-4200" -> "0923-4800"
```

其余（控制逻辑 / 遥测 / 按键）**全部 4200 原样**。
（4300/4400/4500/4600/4700 都是为了测这个数搭的脚手架，已清除。）

### 为什么基准选"从进圈起算"

| 基准 | 后果 |
|---|---|
| **从进圈起算**（默认 `FROM_START 0`）| 与"车从哪儿发车"**完全无关**；对右直角弯**天生免疫** |
| 从起步起算（`FROM_START 1`）| 车只要跑够 403mm 就转，**与赛道位置无关** —— 不是从葫芦圈入口发车就会乱撞 |

**"完全没转"时的第一招**：把 `GOURD_EXIT_ODOM_FROM_START` 改成 1 试一次
（那说明 403 是从起点线量的，不是从葫芦圈入口量的）。

### 同一天还确认的几条工程事实

* **`LED1 = PC13`**（`main.h:60`）。全工程只有 `CAR_EMERGENCY`（150ms 快闪）
  和 `CAR_STOPPED`（250ms 慢闪）会让 LED1 闪，两处都在 `enter()` 里**无条件**调用 `print_odom()`。
  ⇒ **"PC13 在闪" 等价于 "`print_odom` 执行过"** —— 一个很有用的诊断等式。
* **`speed_update()` 全工程只有 `telemetry_report()` 调用它。**
  任何"静默 / 关遥测"的改动，判断必须放在 `speed_update()` **之后**，
  否则测速冻结 → `GOURD_IG_MIN_RPM`（"车确实在跑"）失效。
* **往字符串字面量里加中文会触发 ARMCC `#870-D`**（源文件 UTF-8，ARMCC 按 GBK
  双字节规则扫）。**字符串字面量一律用英文**；注释里中文没问题。
* **里程流模式**（10Hz 只发 `OD=xxxxmm`）是很有效的**串口链路体检**手段 ——
  连它都看不到，问题就一定在链路上（TX 是否接 PA9 / 共地 / 端口 / 波特率），
  与固件无关。
* **两个 USB 同时插（ST-Link + USB-TTL）会因地环路把串口搞死** —— 跑车前必须拔 ST-Link。

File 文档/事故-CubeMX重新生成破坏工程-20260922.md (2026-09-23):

# ⚠️ CubeMX 重新生成会破坏工程 —— 事故记录与恢复步骤

> **2026-09-22 21:00 真实事故**：在 CubeMX 里勾了 FreeRTOS 并点"Generate Code"，
> 结果把工程搞到**完全编译不过、车也不动**。本文记录损失、恢复步骤、以及怎么防。
> **给接手的人：动 CubeMX 之前先看本文。**

---

## 一、事故时间线

| 时间 | 事件 |
|---|---|
| 09-22 **20:55** | 最后一次**能编译、能跑**的固件（`test16.hex`） |
| 09-22 **21:00:54~21:01:06** | 在 CubeMX 里加 FreeRTOS → **Generate Code** |
| 09-22 21:00:57 | `main.c` / `main.h` / `stm32f1xx_hal_conf.h` / `gpio.c` / `stm32f1xx_it.c` / `i2c.h`? 被重写 |
| 09-22 **21:00 之后** | **一直没编译过** —— 所以破坏一直没被发现 |

---

## 二、损失清单（重新生成造成的）

| # | 损失 | 证据 | 严重度 |
|---|---|---|---|
| 1 | **HAL I2C 源文件被删** | `D Drivers/.../stm32f1xx_hal_i2c.c`（**7669 行**）+ `.h`（738 行） | 🔴 直接编译失败 |
| 2 | **I2C 模块被关** | `stm32f1xx_hal_conf.h:49` 变成 `/*#define HAL_I2C_MODULE_ENABLED */` | 🔴 MPU6050 全废 |
| 3 | **按键 PB9 定义被删** | `main.h` 少了 `KEY_START_Pin` / `KEY_START_GPIO_Port`；`gpio.c` 少 14 行 | 🔴 启动键失效 |
| 4 | **FreeRTOS 塞进 `main.c`** | 在 `while(1){app_loop();}` **之前**插了 `osKernelStart()` | 🔴 **车完全不动**（见下节） |
| 5 | 工程文件被改 | `.mxproject` / `test16.uvprojx` / `test16.uvoptx` / `test16.ioc` | 🟡 |

> **关键教训**：CubeMX 的"Generate Code"不是只生成它管的文件 ——
> 它会**按当前 `.ioc` 的内容**重写 `main.c` / `main.h` / `hal_conf.h` / `gpio.c` / `it.c`，
> 并且**删掉它认为你不再需要的 HAL 模块源文件**。
> 只把内容写在 `USER CODE BEGIN/END` 区里是**不够**的（见第四节）。

---

## 三🔴、最致命的一条：`osKernelStart()` 永不返回

重新生成后 `main.c` 变成：

```c
app_init();

osKernelInitialize();     /* ← CubeMX 加进来的 */
MX_FREERTOS_Init();       /*    只建了一个空任务 StartDefaultTask */
osKernelStart();          /*    ★永不返回 */

while (1) {
    app_loop();           /* ★循迹/测速/串口全在这里 —— 永远执行不到 */
}
```

**FreeRTOS 规定：`vTaskStartScheduler()` / `osKernelStart()` 一旦成功启动调度器就接管 CPU，
永不返回**（只有 heap 不够、调度器启动失败时才返回）。
而 `MX_FREERTOS_Init()` 建的 `StartDefaultTask` 里是：

```c
for(;;) { osDelay(1); }    /* 什么也没做 */
```

→ **结果是：初始化跑完，然后进入一个空转的死循环，车一动不动。**

**已修**：`main.c` 里把这三行包进 `#if 0`（保留代码、写明原因）。

---

## 四、恢复步骤（本次实际做的）

```powershell
# 0) 先备份当前被破坏的版本（万一要对比）
mkdir _bak_cubemx_2100
copy Core\Inc\main.h, stm32f1xx_hal_conf.h, stm32f1xx_it.h,
     Core\Src\gpio.c, stm32f1xx_hal_msp.c, stm32f1xx_it.c, test16.ioc  → _bak_cubemx_2100\

# 1) 从 git 恢复 CubeMX 生成的文件（HEAD 就是最后一个能跑的版本）
git checkout HEAD -- `
  Core/Inc/main.h `
  Core/Inc/stm32f1xx_hal_conf.h `
  Core/Inc/stm32f1xx_it.h `
  Core/Src/gpio.c `
  Core/Src/stm32f1xx_hal_msp.c `
  Core/Src/stm32f1xx_it.c `
  Drivers/STM32F1xx_HAL_Driver/Inc/stm32f1xx_hal_i2c.h `
  Drivers/STM32F1xx_HAL_Driver/Src/stm32f1xx_hal_i2c.c
```

**`Core/App/**`（我们自己写的框架）不要恢复** —— 那些是这几天的调试成果，与本次事故无关。

### 然后还要手工改两处

**① `main.c`：停用调度器**
```c
#if 0
  osKernelInitialize();
  MX_FREERTOS_Init();
  osKernelStart();
#endif
```

**② `stm32f1xx_it.c`：让出 SVC / PendSV**

停用调度器后，FreeRTOS 的 `port.c` 仍在编译，它**也定义了**
`SVC_Handler` / `PendSV_Handler`（通过 `#define vPortSVCHandler SVC_Handler`）
→ 链接期冲突：
```
L6200E: Symbol SVC_Handler multiply defined (by port.o and stm32f1xx_it.o)
L6200E: Symbol PendSV_Handler multiply defined (by port.o and stm32f1xx_it.o)
```
→ 把 `stm32f1xx_it.c` 里这两个函数各包一层 `#if 0`。
（`SysTick_Handler` **不用动**：它里面本来就有
`if (xTaskGetSchedulerState() != taskSCHEDULER_NOT_STARTED) xPortSysTickHandler();`，
调度器没启动时只走 `HAL_IncTick()`，正是我们要的。）

### 恢复后的编译结果
```
Code=23604  RO-data=972  RW-data=316  ZI-data=2804
0 Error(s), 0 Warning(s)
```
（对比停用前 `Code=23240 RW=252 ZI=1580`：FreeRTOS 源文件还在编译，
代价是 **Flash +364 字节、RAM +1224 字节**。Flash 占 36%、RAM 占 15%，够用。
想彻底清掉就把 Keil 工程里 `Middlewares/FreeRTOS` 那个分组移除。）

---

## 五、怎么防（**下次点 Generate Code 之前必看**）

| # | 做法 |
|---|---|
| 1 | **动 CubeMX 之前先 `git commit`** —— 这次能救回来全靠 git HEAD 是好的 |
| 2 | **生成后立刻编译一次**，别等下次上车才发现（这次就是拖了 5 分钟没编，一直没发现） |
| 3 | **生成后必查三处**（README 里原来就写了，这次又中了两处）：<br>· `usart.c` 的 USER CODE 区要保留 WordLength/StopBits/Parity/**Mode** 四行<br>· `main.c` 的 `#include "app.h"` 必须在 USER CODE 区<br>· `.ioc` 里编码器枚举要写 `TIM_ENCODERMODE_TI12` |
| 4 | **额外必查（本次新增）**：<br>· `stm32f1xx_hal_conf.h` 的 `HAL_I2C_MODULE_ENABLED` 有没有被注释<br>· `Drivers/.../Src/stm32f1xx_hal_i2c.c` 还在不在<br>· `main.h` 的 `KEY_START_Pin` / LED 引脚定义还在不在<br>· `gpio.c` 的 `KEY_START_Pin` 初始化还在不在<br>· `main.c` 有没有被塞 `osKernelStart()` |
| 5 | 手工加的自定义内容（`MX_I2C2_Init()` 调用、`app_init()` 等）**务必写在 `USER CODE BEGIN/END` 区内**，否则下次生成就没了 |

---

## 六、FreeRTOS 到底该不该用（结论）

**当前不用。** 理由：

1. **现在用不了**：`osKernelStart()` 挡住 `app_loop()`，一启用车就不动。
2. **单任务跑它没收益**：这套代码是干净的"超循环 + 时间戳节拍"架构
   （`app_loop()` 里按 `HAL_GetTick()` 判断各节拍），本来就不需要 RTOS。
3. **真要迁移是个完整小工程**：必须把 `app_loop()` 拆成任务，
   并且给 **I2C(MPU6050)** 和 **UART(遥测)** 加互斥保护
   ——两个任务同时用同一条 I2C 会互相踩。

**唯一真正能受益的点**（如果以后要做）：
- 遥测那行 240 字节以 115200 发送要**阻塞约 21ms**，会顶掉一拍控制周期
  → `DT=` 会看到偶尔 21~31 而不是稳定 10
- 用 FreeRTOS 把"控制"放高优先级任务、"遥测"放低优先级任务，可以消掉这个抖动
- ⚠️ 但**航向角积分已经改成用实测 dt 了**（见 `imu.c` 的 `yaw_last_time`），
  所以这个抖动对 90° 转弯的精度**已经不再是问题** → 也就没那么必要上 RTOS

**结论：留文件、不启用。等把车调稳跑通了，如果还有空闲再考虑。**

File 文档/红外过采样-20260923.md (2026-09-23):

# 红外采样过采样（提高实际采样频率）— 2026-09-23

> FW `0923-2010` 起生效。改动只落在 `line_sensor.c/.h` + 三个遥测字段，
> **没有动队友的十字/葫芦判据逻辑**。

---

## 一、原来为什么不够

| 项 | 值 |
|---|---|
| 控制拍 | `CTRL_PERIOD_MS = 10ms` → 100Hz |
| 红外采样 | **每拍只读 1 次 = 10ms 一次** |
| 车速 | 约 1.2m/s（满 PWM 99） |
| **拍间位移** | **10ms × 1.2m/s = 12mm** |
| 白线宽 | 25mm |

**12mm 的拍间位移 和 25mm 的线宽是同一个量级** → 进/出口那种"一闪而过"的图案
（比如只持续几毫秒的分支口）**可能整拍被跳过**，时序判据就不稳。

---

## 二、怎么做的：一拍内【突发采样】

单次读 8 路只要 **~16 个 CPU 周期**（位带读，1 周期/位），72MHz 下 ≈ **0.22µs**。
所以一拍内连读 N 次几乎不花时间。

```
控制拍边界
   │
   ├─ 子采样#1 ─(1µs)─ #2 ─(1µs)─ #3 ... #8      ← 突发（共约 10µs）
   │
   ├─ 表决 → 1 个读数
   │
   └─ 正常跑这一拍的循迹/PD/速度环（剩余 ~10ms 不变）
```

**实现位置**：`line_sensor.c` 的 `line_read()` **内部**。
所以**三个调用点（循迹 1 处 + 遥测 2 处）自动受益**，上层一行都不用改。

### 表决策略（`LINE_OS_VOTE_MAJORITY`）

| 值 | 策略 | 取舍 |
|---|---|---|
| **1（默认）** | **多数表决**：某路 ≥半数 子采样为亮才算亮 | 压毛刺；`active`/`dark_groups` 与单采样同量级 → **不影响十字/出口判据** |
| 0 | 按位或：任一子采样亮就算亮 | 绝不错过任何一次亮；但 `active` 偏大 → 可能让"宽图案(≥5路)"更容易触发 |

### ★一个必须守住的约束：`error` 与 `raw` 必须同源

`error` **不是**把 N 次的 error 求平均，而是**由表决后的位图算出来**。
原因：平均出来的方向可能对应一个**不存在的图案**，会和"按位图做图案匹配"的判据打架。

---

## 三、配置（`app_config.h`）

```c
#define LINE_OS_ENABLE       1    /* 总开关 */
#define LINE_OS_SAMPLES      8    /* 每拍突发几次（1~64） */
#define LINE_OS_SPACING_US   1    /* 子采样间隔(µs)，0=背靠背 */
#define LINE_OS_VOTE_MAJORITY 1   /* 1=多数表决 0=按位或 */
```

**耗时核算**：`N=8、间距1µs` → 一拍内 ≈ `8 × (1 + 0.22) ≈ 10µs` = 10ms 的 **0.1%**。
即使每拍被 `line_read()` 调用 3 次，也只有 **0.3%**，可忽略。

调整方向：
- 想更稳 → 加大 `LINE_OS_SAMPLES`（但 `DT=` 必须还是 10）
- 想更快 → `LINE_OS_SPACING_US = 0`（背靠背，约 0.22µs/次）

---

## 四、怎么**验证它真的起作用**（不用改代码）

遥测加了两个字段：

```
FW:0923-2010 IR:10110010 RPM1=.. DT=10 OS=7 GZ=.. GW=.. ...
                                ↑      ↑
                          实测控制周期  本窗口内"子采样位图不一致"的拍数
```

| 字段 | 看什么 | 结论 |
|---|---|---|
| **`DT`** | 是否稳定在 **10** | `DT > 15` → 主循环被拖慢（过采样太多，或 IMU 的 I2C 阻塞） |
| **`OS`** | **是否 > 0** | **`OS > 0` = 快采样确实抓到了单次采样会漏掉的东西 → 过采样在起作用**<br>`OS = 0` = 这几个 µs 内红外完全没变（模块跟不上 / 间距太小 / 关闭了） |

### 判读流程

1. **静止**（车不动）：`OS` 应该 **= 0**（红外不变）。如果是 0，符合预期。
2. **跑起来**：`OS` 应该 **> 0**。这就是"采样率提高带来了新信息"的直接证据。
3. 如果**跑动时 `OS` 仍然一直是 0** → 说明红外模块本身跟不上（板载滤波/比较器延迟），
   提高 GPIO 采样率没用。这时该考虑的是**换模拟量输出 + ADC**，而不是继续拉高采样率。
4. 如果 **`DT` 明显 > 10** → 把 `LINE_OS_SAMPLES` 调小（8→4）或 `LINE_OS_SPACING_US` 调 0。

`OS` 是"读一次清一次"，所以它表示**这一行遥测间隔内涨了多少**（运行中 50ms 一行 → 约 5 拍）。

---

## 五、⚠️ 诚实说明：这是"突发采样"，不是"真·连续采样"

| | 本方案 | 真·连续采样 |
|---|---|---|
| 拍内 | 连采 8 次（≈10µs） | 全程连续 |
| 拍间（约 9.99ms） | **仍然不采** | 连续 |
| 需要动的东西 | 无（只改一个函数） | 定时器中断 或 ADC+DMA（要动 CubeMX） |

**为什么先做这个**：零风险、不动外设配置、三个调用点同时受益，
且"把整拍漏掉的窄图案救回来"这个目标它就能达成。

**如果还不够**（`OS` 一直 0，或时序判据仍然不稳），下一步才是：
- 方案 A：`CTRL_PERIOD_MS` 降到 5ms（控制 200Hz）—— 但要同步复核速度环的 `dt`、加速/减速斜坡
- 方案 B：TIM 中断里以 1kHz 采红外，主循环只取最新值（要动 CubeMX，风险较高）

---

## 六、未验证项（如实记录）

- ❌ **没上车实测**。`OS`/`DT` 的实际读数我一次都没看到过。
- ❌ **不知道红外模块能跟上多快**。0.22µs 是 *GPIO 读取* 的上限，
  不是 *模块输出* 的上限 —— 这是两回事，只能靠 `OS` 实测判定。
- ❌ **DWT 是否在这颗芯片上正常使能**没有实测确认。
  代码里做了兜底：若 `DWT->CTRL` 读回没使能，`dwt_ok=0`，退化为"背靠背采样"，功能不受影响。
- ⚠️ 表决会**轻微平滑**掉真实快速跳变。若发现"某个图案反而更难抓了"，把
  `LINE_OS_VOTE_MAJORITY` 改成 0 试。

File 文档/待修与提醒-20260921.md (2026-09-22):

# 待修与提醒 — 2026-09-21

> 来源：ZCode 代码复查（读了 `Core/App/control/line_follow.c`、`Core/App/fsm/car_fsm.c`、
> `Core/App/app_config.h`、`Core/App/telemetry.c` 之后整理的）。
> **约定：这个文件只记录问题 + 复现/验证方法，不改代码。** 改不改、怎么改自己定。

---

## 🔄 2026-09-22 复查更新（通读整个工程后）

**老条目现状**

| 原条目 | 现状 |
|---|---|
| 一、丢线 uint8 回绕 | ✅ **已修**：`lost_cycles` 改成 `uint16_t`，超限时钉死在 `LOST_MAX_CYCLES+1` → "停车防跑飞"现在真的生效。（原复现步骤留作回归测试用）|
| 二、葫芦靠哪一层过（纯兜底） | 🔄 **已被新方案取代**：9/22 固件有了**"葫芦弯相切点状态机"**（`USE_GOURD_SM`）|
| 三、搬 test161 的固定数组 | ⏭️ **没搬，也不建议搬** —— 现在这套"相切点计数 + 翻转修正"更贴合你的车（不绑速度）|

**新增（按重要性排序）**

### A. ⚠️ 葫芦状态机可能"误触发"，且你现在的遥测就能验证
判据是"**最外路亮(≤2 路) → 3 拍内扩散到 ≥3 路**"。但**直角弯入口、十字入口、丢线恢复**都会产生同样的"边缘→扩散"波 → 都会被记成一个"相切点"，并在之后 15 拍内一旦丢线就**反向修正**（`-gourd_dir*3`）。赛道上有 **3 个直角弯 + 2 个十字**，撞上的机会不小。

**验证（免费，不用改代码）**：跑完整圈，看遥测里的 **`GW`** 值。
- 正常应该是 **3**（4 个相切圆 = 3 个相切点），绕完清零；
- 如果在直角/十字处 `GW` 乱涨（比如跑到 5、6 然后清零），就是误触发已经在发生。

**若要加闸门**：用你刚启用的 **IMU** 最省事 —— 真相切点处**偏航率 `GZ` 会翻转符号**（左转→右转），直角弯处不会翻。`GZ` 已经在遥测里印了，直接可用。只在"GZ 符号翻转"时允许开 `gourd_flip` 窗口，误触发就能压掉一大半。

### B. 🔧 魔数 `3` 没进 `app_config.h`
`line_follow.c:136` 和 `:182`：`e = (int8_t)(-gourd_dir * 3);` —— 这个"翻转修正力度"是**硬编码**的，改它必须动 `.c`。这违反本项目"**唯一调参入口 = app_config.h**"的约定（你自己在 README 里写的）。建议提成 `GOURD_FLIP_ERR`。

### C. 🔧 直线提速是"瞬跳"，没有斜坡
`sp = STRAIGHT_BOOST_SPEED(99)` 一满足条件直接从 70 跳到 **99**（满 PWM），退出却是"误差一大立刻回落" = 慢起快落。
→ 如果提速那一瞬间车会**一顿/摆一下**，先别怀疑 KP，给个斜坡（每拍 +2~3）试；另外 99 已是满 PWM，留点余量（95）通常更稳。

### D. 📄 注释与实现不符（会误导下一个人）
`line_follow.c:68` 注释写"3 次 = 绕完 4 个圆 → **退出**"，但代码只是把 `gourd_waves` 清零——**没有"退出"状态**（这个 SM 是无状态的建议器，只影响丢线时的修正方向）。行为没问题，注释该改。

### E. ✅ 位序核对通过（读日志时按这个读）
`line_sensor.c:23` 用 `r.raw |= 1u << i`，`i` 跟着 `LINE_CHANNEL_TABLE`（左→右）→ **bit0 = 最左（权重 -7）、bit7 = 最右（+7）**。
所以遥测里 `IR:` 的**第一个字符就是最左侧那一路**，`IR:10110000` = 从左数第 1、3、4 路亮。`raw & 0x01 / 0x80` 用得对，没问题。

### F. ⚠️ 串口 RX 的状态自相矛盾，要确认
`README.md`（9/22）把串口命令表当可用功能写；`代码交接说明-20260921.md` 的"已知问题"里写着 **"串口 RX 收不到 → 待修"**。
**如果 RX 真收不到，`P/S/D` 在线调参就全废**（只能改宏重烧），调车效率差一个量级。→ 插上串口发一条 `V`，看有没有回；不会回就是还没修好。

### G. ✅ 已结清（2026-09-22 复查）：丝印 logo **有**，不用担心检录
**结论：`硬件设计/寻迹小车板子V3_PCB1_20260918_181854.zip` 的顶层丝印（GTO）里已经印着
`2026机器车循迹 Suika Lab`** —— 位置在板子中部偏右、TB6612（U4）模块框上方约 1.5mm 处，**在板框内、没被任何模块焊盘压住**。

规则原文要求的是"主控/驱动/传感器**任选其一**"有即可 → 这块板就是主控板 → **满足**。

**怎么核出来的**（下次要看板子长啥样可以直接复用）：
- Gerber 是 EasyEDA Pro 导出的 RS-274X，**丝印在 `Gerber_TopSilkscreenLayer.GTO`**（`GBO` 背面丝印是空的，只有框）
- 用 `_tmp/pcbv3/render.py`（我写的小渲染器：解析 `%ADD..%` 光圈表 + `G54D<n>*` 选光圈 + `G01X..Y..D01/D02` 画线，PIL 出 PNG）渲染成图直接看字
- 顺带量出：**板框 = 70.000 × 90.000 mm，四角 R3**（`Gerber_BoardOutlineLayer.GKO`）；丝印上那两个"62.000mm / 83.000mm"标注 = **PCB 安装孔距 62×83**（和他自己报的 `PCB 90×70、孔距 83×62` 完全对上 ✓），不是板子外形尺寸
- ⚠️ 小瑕疵（不影响检录）：那两个尺寸标注线/箭头**画到了板框外**（左边缘到 x=−26.8、上边到 y=+11.7；板框只有 −19.4..50.6 / −87.8..+2.2，共 346 个点越界）→ 工厂按板框裁切后会剪掉，出不来字，纯属图面残留，**不用改版**。

**剩下的唯一确认（1 秒）**：`Suika Lab` 要和你**报名登记的队名**一字不差；再有就是拿到板子实物瞄一眼顶面那块字在不在（打样没漏印就行）。

---

## 一、待修 Bug：丢线"停车防跑飞"被 uint8 回绕抵消了

**位置**
- `Core/App/control/line_follow.c:15` —— `static uint8_t lost_cycles = 0;`
- `Core/App/control/line_follow.c:86-99` —— 丢线旋转 / 停车分支
- `Core/App/app_config.h:64` —— `#define LOST_MAX_CYCLES 150`

**当前代码**

```c
if (line_lost)
{
  if (lost_cycles > LOST_MAX_CYCLES) { motor_stop(); }        /* 设计意图: 找不到线就停车防跑飞 */
  else if (last_error >= 0) { motor_set_differential( 35, -35); }
  else                      { motor_set_differential(-35,  35); }
  return;
}
```

**问题**：命中停车分支后 **`lost_cycles` 没有重置**，而它是 `uint8_t`。

| 拍数 | 行为 |
|---|---|
| 0–2 | 短暂丢线：`e = last_error × 2` 沿原方向修正 |
| 3–150 | 原地旋转找线（±35） |
| 151–255 | `motor_stop()` 停住 |
| **256（回绕）** | `lost_cycles` 变成 0 → **又回到"旋转"** → 再停 → 再转… |

**实际行为**（1 拍 = `CTRL_PERIOD_MS` = 10 ms）：**转 1.5 s → 停 1.05 s → 又转 1.5 s → …** 无限循环，永不真正停住。
→ "防跑飞"这个安全设计**被类型回绕抵消**了：丢线时车会在原地一直打转。

**两种改法（选一个，并把意图写清楚）**
- **想真停**：`lost_cycles` 改 `uint16_t`，或在停车分支里把它钉死（`lost_cycles = LOST_MAX_CYCLES + 1;`）+ 给个 `stopped` 标志；
- **想要脉冲搜索**（"停一会再找"）：把现在这个行为**显式写成**"停 N 拍后重试"，别靠类型回绕来兜。

**2 分钟复现**：车架空（四轮离地）、用纸/手把 8 路传感器全挡住 → 计时看轮子：
按设计应约 1.5 s 后停住；**实际是停 ~1 s 后又自己转起来**，如此反复。

---

## 二、待确认：葫芦弯到底是靠哪一层过的（test17 里**没有**葫芦状态机）

`line_follow.c` 里只有四样东西，没有 GOURD 状态：速度自适应 / 十字判定 / 丢线兜底 / PD。
能过葫芦靠的是三套**通用**兜底凑出来的：

| # | 位置 | 干什么 |
|---|---|---|
| ① | `line_follow.c:38-51` | 速度自适应：`\|e\| ≥ CURVE_ABS_ERR_THRESH(3)` → 降到 `sp_curve`（60 → 42） |
| ② | `line_follow.c:68-72` | 短暂丢线：`e = last_error × 2`（沿上次方向**加倍**修正） |
| ③ | `line_follow.c:86-99` | 持续丢线：原地旋转找线 |

**验证方法（别推理，用数据）**：跑动时遥测是 **20 Hz**（`app_config.h:54`，`TELEMETRY_PERIOD_RUN_MS 50`）。
把过葫芦那几秒的串口日志存下来，看 `IR:` 位图：

- **从不出现 `00000000`** → 是 **①降速 + PD** 过的，兜底没参与（说明当前几何/25 mm 线宽下葫芦并不难）；
- **全 0 后 1–2 拍恢复** → **②在救**；
- **全 0 且长时间维持**（`ST` 停在丢线态很久）→ **③在救** → 同时去看第一节那个 Bug。

**第②层的失效模式**：`e = last_error × 2` —— 如果丢线那一刻车**正好居中**（`last_error ≈ 0`），
翻倍还是 0 → **不修正，直着冲出去**。相切点恰好压中心时就会撞上。

---

## 三、以后把 test161 的葫芦逻辑搬进来时，注意三件事

参考实现：`..\test161\Core\Src\main.c`（**参数在第 42–47 行，状态本体在 169–201 行**）
`GOURD_ENTRY_HOLD 3` / `GOURD_STEP_BEATS 4` / `GOURD_STEER 30` / `GOURD_SPEED_PCT 60` / `GOURD_MAX_CYCLES 150`

1. **图案撞车（最危险）**：test161 里 终点 = `10101`、葫芦 = `00101`，**只差最左一路**，而 TRACK 中**先判终点**。
   进葫芦时车位稍歪、最左被扫到 → 会被判成**终点 → 停车自锁**。
   → 解药就是你新 FSM 里留的那个 TODO：**终点 = 图案 + 里程双条件**（`Core/App/fsm/car_fsm.c:128`）。**先做这个，再搬葫芦。**
2. **别按"拍"打节奏**：test161 那个固定数组是按 10 ms 拍数计的 → **绑死速度**，一改 `BASE_SPEED` 就得重调 `GOURD_*`。
   → 改成按**编码器脉冲（距离）**计数：编码器已配好（`app_config.h:112-120`，TIM3/TIM4 正交解码，422 PPR）。
   正好是 W3 那条线，而且不再绑速度。
3. **保留现有兜底**：test17 这套"降速 + 丢线加倍修正 + 旋转找线"对入口角度更鲁棒。
   搬状态机时**把它留作 fallback**（认不出葫芦就照常循迹），不要只留开环节奏。

---

*本文件只记录问题与验证方法，不含任何改动。*

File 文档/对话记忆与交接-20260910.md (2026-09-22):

# 对话记忆与交接（2026-09-10，更新至 2026-09-11）

> **用途**：本对话快满，换新对话时**先读这份** + `新车设计书.md` + `开发进度与交接.md`。
> **写给**：以后的我（Claude）、以及用户自己。

---

## 0. 一句话现状
正在**从零设计一辆新车（自研 PCB + SolidWorks 结构）**，设计**已定稿**（2026-09-11 下午待定项全清：PCB 不兼作底板、电源外置小模块）；
**下一步 = 按新车设计书 §八清单下单 + 出 PCB 布局图**；代码框架（test17）就绪。

---

## 1. ★协作约定（Claude 必守）
1. **用户最大的问题是"动手前没想清楚细节 → 反复返工"**。**以后每次动手（下单/买件/画PCB/画底板/搭车/写代码）前，Claude 必须主动按 `动手前考虑清单.md` 帮用户把关**（尺寸、配套耗材、装起来会怎样、最大风险、兜底），不用用户提。
2. **学习方式**：用户**自述理解 → Claude 批改 + 写 CSDN 文章**（文章结构：定义/内容 → 举例 → 提出问题；问题由用户自产）。

---

## 2. 已在做的事：新车设计
> 详细见 **`新车设计书.md`**（主文档）。

### 2.1 已定决策（别再翻案）
- ✅ **8路循迹**：**外接现成模块**（PCB 留 8-pin 接口），不自绘
- ✅ **状态显示**：**撤销 OLED** → **LED×3 + 蜂鸣器**（无源PWM）+ **启动按键**
- ✅ **启动方式**：按键 → **3s读秒（LED逐个亮 + 蜂鸣3声）** → 开始循迹
- ✅ **新板用新 C8T6** → PB8/PB9 可用（旧芯片那两脚坏）
- ✅ **电机**：先用 **2× JGA25-370 620rpm/9.6:1**（备选升级 280@21.3）
- ✅ **电池**：7.4V 2200mAh **暂不换**

### 2.2 实测数据（关键，别丢）
| 项 | 数值 |
|---|---|
| 驱动轮直径 | **6.6cm** → 半径 3.3cm → 轴心离地 **3.3cm** |
| 底板尺寸 | 长 **18.5cm**；宽 前 **7.5** / 中 **13.5** / 后 **15.7cm** |
| 轮距（后轮） | ≈15.7cm |
| 8路红外模块 | 长 **9cm** × 宽 **3cm**（无支架，背面2个1.7cm长条孔）|
| 电池 | 长 **6.4cm** × 宽 **3.5cm**（高度待补）|
| 电机支架孔 | **1.7cm 正方形四角**，孔径 **3.5mm** → M3 螺钉 |
| 降压板 | 宽 **4.4** × 长 **6.7cm** |
| PCB | **9×7cm（90×70mm）**，4 安装孔孔距 **83×62mm** |
| 学长车参考 | 前**麦轮半径3cm**（嵌入车身）|
| 编码器 PPR | 11×9.6 ≈ **106**（先填这个，装好手转核对）|

### 2.3 ★核心设计原则（防翘头等式）
> **前支撑（麦轮/万向轮）高度 必须 = 驱动轮半径 = 3.3cm**，否则翘头。
> 且**前支撑必须全向**（差速车要能原地转，否则急弯卡住）。

### 2.3+ ★2026-09-11 新增决策（本次对话成果）
- ✅ **前支撑类型 = 麦轮，但必须装 0°**（滚子轴线垂直于前进方向），**不许 45° 装**
  - 理由：45° 时滚子自由滚动方向与实际速度方向差 45° → 需 71% 侧向滑移
    → 前轮负载 ~200g 时产生 **≈1.1N 刮擦阻力**；0° 装 = **0N**
  - 更致命：麦轮一圈内装角在 0°↔45° **周期脉动** → 急弯"时抓时滑"、原地转卡顿
  - 且它是**被动轮**，四麦轮"侧向力两两抵消"的前提不存在 → 优点全丢、缺点全留
  - 0° 装等效于"不带叉子的万向轮"，成立
  - 备选：球脚轮（推荐备选）＞双轮万向脚轮＞滑撬；❌ 麦轮 45° 不推荐
- ✅ **高度可调机构（防返工关键）**：底板底面用 **M3 铜柱 + 垫片** 吊住支撑，
  买回的高度**不用刚好**，凑到 3.30cm 即可。
  ★2026-09-11 下午修正：**堆叠 = 3.30 − 裸高**（原表把堆叠写成 = 裸高，照装总高 6.0cm、车头翘 2.7cm）；
  **推荐买 60mm 麦轮**（裸高 3.0 → 只需 3mm 垫片；麦轮轴用 M3+尼龙锁紧螺母留旷量自由转）
  → **下单清单：M3铜柱 20/25/30/33mm 各4根 + 5mm×4（PCB用） + M3垫片 0.5/1/2/3mm 各20片 + 60mm麦轮×2**
- ✅ **电池高度 = 1.8cm**（长6.4×宽3.5×高1.8，⏳待卡尺实测复核）
- ⚠️ **关键定尺（2026-09-11，❌ 2026-09-18 部分作废：实际为"复刻学长车"，非我们自算方案）**：轴距 ~~8.5cm~~⏳待实测、传感中心距驱动轴 ~~5.0cm~~ → **实测 213mm**、轮距 ~~11.7cm~~⏳待实测、
  PCB抬高到离地 **4.0cm**、底板长 **18.5cm 定稿**、整车 18.5×15.7×≈6.6cm（核心板插座 ≈+1cm）
- ✅ **重心 x_cg ≈ −0.7cm（轴后0.7，仍基本压驱动轴）** → 前支撑静载 **≈8%(83g)**、驱动轮各 **≈46%**
  （★2026-09-11 下午重算修正：原 +0.1/1% 系力矩加错；结论不变——后驱优、前支撑必须触地）
  - 好处：牵引力最优（后驱最怕重心靠前打滑）、原地转前轮无阻力
  - 代价：**前支撑几乎不承载、只防点头** → 规格要求极低，但**必须接触地面**
    （差1mm悬空就点头/抖）→ **可调高度机构是必须项**
  - 兜底：电池/PCB 用**长条孔**，允许 **±2cm 纵向滑动调重心**（装好后仍可调）
- ⏳ **待复核**：前支撑裸高、电池高度实测、整车称重、三点着地（塞尺垫不进0.5mm）

### 2.3++ ★2026-09-11 下午新增决策（待定项推进，本次对话成果）
- ✅ **PCB 不兼作底板**：底板 18.5×15.7 超廉价打样 10×10 上限、几何未实测 → **3mm 亚克力激光切割**验证，
  PCB 保持独立 **9×7cm（90×70mm）** 抬高 4.0cm；4 安装孔孔距 **83×62mm**（孔位从 PCB 图读出，见 底板布局草案 §四）；兼作记 v2 备选
- ✅ **电源 v1 = 外置小降压模块**（MINI360 ≈2.2×1.8 / MP1584 模块 ≈3.6×2.2，→5V，¥3~5）+ 板上 AMS1117-3.3→3.3V；
  ★**大模块 4.4×6.7 经布局逐位置核实全车无处安放**（电机区/PCB区/前宽7.5/电池旁纵向全冲突）→ 退役留旧车；
  v2 板上集成备选：MP1584EN（首选，4.5-28V/3A/SOP-8）/TPS5430（5.5-36V/3A/500kHz）
- ✅ **J_LINE8 接口 8-pin → 10-pin**（8信号+VCC+GND，原设计漏电源脚）
- ✅ **J_POWER 定 4-pin**（7.4V+ / GND / 5V_IN / GND，板上共地）
- ✅ **降压小模块安装位**：板顶后部中央 x≈−6.8、z±1.8（已写进 底板布局草案 §1.4/§2.1/§四）
- ✅ **代码：ENCODER_PPR 11 → 106 已填**（Keil 编译核验 0 错 0 警）
- ✅ **主控改用成品 C8T6 核心板插底板**（2026-09-11 晚，用户定）：底板=纯载板（排母×2 插核心板）减少接线；
  **晶振(8MHz)/BOOT0/复位核心板自带，底板不买不接**；核心板走 5V 脚（板载 LDO 出 3.3V），
  底板 AMS1117 的 3.3V 只给 MPU6050/编码器/LED（两路 3.3V 不并联）；
  ★核心板**必须用新芯片的板**（PB8/PB9 要用，旧板坏）；BOM 已换：核心板×1 + 排母 1×20 ×2（删 芯片/晶振/最小系统件）；
  ★画底板前实测核心板插针行距/外形 → 定插座孔位
- ✅ **蜂鸣器引脚修正（2026-09-11）**：原 **PB8 = TIM4_CH3** 与右编码器（TIM4 正交解码）**同定时器冲突** →
  改 **PA11 = TIM1_CH4**（PB8 转备用）。CubeMX 配 TIM1 CH4 PWM Generation；想省事可换**有源**蜂鸣器（不需 PWM，PB8 即可）
- ✅ **蜂鸣器驱动电路定稿（2026-09-11，照抄现成参考图）**：S8050(SOT-23) 低边开关 + R61 1k 基极 + **R62 10k 基极下拉（防上电乱响）**
  + D10 DSK14 续流 + C72 0.1µF 去耦 + R60 0Ω 跳线可选；**参考图信号脚是 PA8 → 必须改 PA11**（PA8=循迹第3路）。电路图存 `新车设计书.md` §3.5
- ✅ **启动按键接法**：4 脚轻触 KH-6X6X5H 内部 1-2/3-4 通 → **每排两脚都连**（上排→PB9、下排→GND）+ 0.1µF 消抖
- ✅ **PCB 已下单（2026-09-15，嘉立创）**：**9×7cm**、2 层、FR-4、**1.6mm**、白阻焊/黑字符、**有铅喷锡**（手焊好焊）、
  外层铜厚 **1oz**、过孔盖油、线路全测、无 SMT、**5 片 ¥30**；预计 **2026-09-18 晚发货**
  → ★到货后流程：目视 + 万用表先测 **5V/GND 是否短路** → 上电测 5V/3.3V → **最后才插核心板**（防烧板）；
  ★下单后仍需核：**核心板排母行距与实物一致**（图上标 12.800mm）、大电流走线宽度（1oz 建议 ≥1.5mm）
- ★**BOM 核对（2026-09-16，`BOM_Board1_Schematic2_2026-09-16.xlsx`）**——板上件：XH-2P×4（3.3V/5V/URAT/VM）、
  蜂鸣器 QMB-09B-03(9mm)、SS8050+1N4148W(SOD-123)+1k+10k+100nF、20P 排母×2 + 20P 排针×2（核心板）、
  8P 排母×3（MPU6050 + TB6612 两排）、6P **PH2.0**×2（电机）、10P（8路）、4P 轻触 KH-6X6X5H、TVS PTVS6V0S1UR（加分项）
  **缺件/待补**：① **无大电容**（VM 100~470µF、5V/3.3V 10µF+0.1µF 全缺，全板仅 1 个 100nF）→ 手焊时并在对应 2P 连接器焊盘上
  ② 无 AMS1117（3.3V 靠核心板经「3.3V」2P 引入？需确认，负载 ~50mA 核心板 LDO 可扛）③ UART 仅 2P（设计要 4P VCC/GND/TX/RX）
  → 电源从 5V 口取、TX/RX 走 URAT ④ 无 SWD 4P 座 → 用核心板 SWD 口或杜邦线引 PA13/PA14 ⑤ LED 仅 3×2P 排针，
  **无灯珠/限流电阻** → 串在线里（PC13 那颗 4.7k）⑥ 按键无消抖电容 → 软件消抖或手并 0805
  **待确认**：蜂鸣器 QMB-09B-03 是否**无源**；电机插头 PH2.0 vs XH2.54；U5 TVS 是否在 5V 轨；核心板排母行距；排母 5V 脚是否接板 5V 网
- ⏳ 仍待实测：前支撑裸高、电池高度、整车称重、塞尺三点着地

### 2.4 待定项（★2026-09-11 更新）
1. ~~前支撑类型~~ ✅ 已定：麦轮 0° + 铜柱垫片
2. ~~电池高度~~ ✅ 已定：1.8cm（待实测复核）
3. ~~PCB 是否兼作底板~~ ✅ 已定（2026-09-11）：**不兼作**，亚克力底板 + 独立 **9×7cm** PCB（v2 再议）
4. ~~DCDC/LDO 选型~~ ✅ 已定（2026-09-11）：v1 外置小降压模块 + AMS1117；v2 集成 MP1584EN/TPS5430
5. ~~轴距/整车长宽高~~ ✅ 已定（见 2.3+）
6. 编码器 PPR 实测核对（✅ 代码已填 106，装好手转一圈核对）

### 2.5 引脚方案（设计书 §3.2）
```
电机: PA2/PA3(PWM) PA4/PA5(左方向) PB3/PB4(右方向)
编码器: PA6/PA7(左,TIM3)  PB6/PB7(右,TIM4)
8路红外: PA0,PA1,PA8,PA15,PB0,PB1,PB12,PB13
MPU6050(I2C1): PB10(SCL)/PB11(SDA)
LED×3: PC13/PB14/PB15   蜂鸣器: PA11(TIM1_CH4 PWM)   启动键: PB9
串口/蓝牙(USART1): PA9/PA10      SWD: PA13/PA14      晶振: 核心板自带(PD0/PD1 不用接)
```

---

## 3. 代码 / 工程状态
- **`test17`** = 重制版工程（Keil），**已重构成分层框架** `Core/App/`：
  - drivers(motor/line_sensor/speed/encoder/imu) + control(pid/filter/line_follow) + fsm(car_fsm) + telemetry + app_config.h
- **`app_config.h` 已是 8路版**：`LINE_CHANNELS=8`、8个引脚+权重、`LINE_ACTIVE_LEVEL=GPIO_PIN_RESET`（白线黑底）、`CTRL_PERIOD_MS=10`、`USE_D_FILTER=1`
- 开关：`USE_ENCODER/USE_IMU/USE_SPEED_LOOP`（默认 0，待硬件配好开）
- **`test161`** = 旧车+滤波+10ms+状态机(含葫芦固定数组)的 Keil 测试工程（桌面）
- **test17 编译核验通过（0错误0警告）**

---

## 4. ★工具环境（重要，刚修好）
- **Keil 已从 C 盘挪到 `D:\Keil_v5`**（C盘满了）：
  - `TOOLS.INI` 里的 C 路径已改成 D（否则报"器件包未安装"）
  - **文件关联注册表已修**（UVPROJXFILE 等 6 个 ProgID → D 盘，HKCU 覆盖）
  - **桌面快捷方式「Keil uVision5」已重建**
- **编译核验方法**：`UV4.exe` 是 GUI，必须 `Start-Process ... -Wait` 才会等它编译完
- **VSCode 跑 STM32**：CubeMX 选 CMake 工具链 → VSCode 打开 → 发 **`/stm32-project-setup`**（固定流程）
- VSCode 学习工程在桌面 `CSDN\`（PC 上跑纯 C 算法）

---

## 5. 学习进度
- ✅ **PID 学完**：P/I/D、整定、进阶三补丁（积分限幅/积分分离/微分先行）、二阶系统 ζ↔D
- ✅ **滤波学完**：一阶低通/滑动平均、α 权衡、为 10ms 铺路
- ⏭️ **下一步**：**状态机 FSM**（十字/葫芦/终点）、编码器用法、MPU6050 用法（HAL I2C 读寄存器）
- 学习产物：`文档/PID控制学习笔记-今日全.md`（注：此文件当前**不在 test17**，可能被挪走，需要可重建）

---

## 6. 文档地图（都在 `C:\Users\asus\Desktop\test17\`）
| 文件 | 内容 |
|---|---|
| **`文档索引与状态.md`** | ★★**新对话先读这个**：哪个文件说了算 / 哪些数据已作废 / 待实测清单（2026-09-18 建） |
| **`新车设计书.md`** | 电气/PCB/电源/BOM/引脚（⚠️ **机械尺寸以"底板布局草案"为准**） |
| **`底板布局草案.md`** | ★**结构尺寸权威源**（顶部：复刻学长车变更说明 + 213mm 前瞻证据链） |
| **`动手前考虑清单.md`** | ★防返工清单（Claude 每次动手前必过） |
| ~~`开发进度与交接.md`~~ | ⚠️ 已标为**历史文档**（旧车开发史/踩坑/CSDN计划） |
| `归档-20260918/` | 旧车资料（画板手册/使用手册）+ 一次性脚本与截图（**别当现状用**） |
| `文档/接线对照表.html` | ✅ **2026-09-11 已同步新版**（见下） |
| `文档/` | 校赛重制版/使用手册/画板手册/CSDN/PID笔记/比赛规则 |
| `脚本/` | tune.ps1 |
| `参考库/` | TC264库、八邻域 |
| `Core/App/` | 分层框架代码 |

✅ **`文档/接线对照表.html` 已同步新设计（2026-09-11）**：
- **删掉了过时的"PB8/PB9 已损坏，不要接任何线"**（那是**旧芯片**的事；
  新车用新 C8T6，PB8=蜂鸣器、PB9=启动键）
- 新增 **第五节「人机：LED×3 + 蜂鸣器 + 启动按键」**（原来完全没有）
- 电机从 N20 改为 **JGA25-370 620rpm**，补 TB6612 STBY、BOOT0、电源树图
- 补关键提醒：**ENCODER_PPR 要从 11 改成 106**、PA15 需关 JTAG、PA10 重新生成后会掉

---

## 7. 踩过的坑（教训）
1. **搭车翘头**：没买匹配的万向轮（前支撑高度 ≠ 驱动轮半径）→ 白装一下午
2. **电机到了没线**：漏买配套电机线/编码器线
3. **C 盘爆满挪 Keil**：挪盘后 TOOLS.INI/注册表路径全串 → 已修
4. **"离地1cm"歧义**：应指**传感**离地1cm（底盘因轮半径3.3cm做不到1cm）

---

## 8. 新对话开场建议
> "先读 `test17\对话记忆与交接-20260910.md` + `新车设计书.md` + `底板布局草案.md`，
> 我们继续推进新车：**① 按 §八定稿清单下单（含铜柱垫片/60mm麦轮/小降压模块）② 出 PCB 布局图 → 画板 ③ 亚克力底板下料 ④ 到货实测复核（见 8.1）**。"

### 8.1 ⏳ 下次接手第一件事（拿卡尺/秤就能做）
1. **量电池最厚处**（含平衡头、线受压处，量最大处）→ 若 >2.0cm，只需把 PCB 铜柱加高，布局不用重画
2. **量前支撑裸高**（触地面 → 顶面）→ 对照 §2.3+ 表选铜柱长度
3. **称整车**（到货后）→ 替换重心估算值（方法在 `底板布局草案.md` §3）
4. **塞尺查三点着地**：前支撑垫不进 0.5mm 才算合格

---
*（本文件为本次对话的记忆快照）*

---

## 📌 2026-09-22（周二）进展 —— 新对话从这里接

> **一句话**：新车 v2（3D 打印底板）跑通；固件 `FW:0922-1500` 已烧录（含锁车修复 + MPU6050 启用 + 直线提速 + 葫芦相切点检测）。

### 今天做完的
1. **MPU6050 启用**：★★**PB10/PB11 上是 I2C2，不是 I2C1**（I2C1 在 PB6/PB7，被编码器占了）—— 文档里长期写的"I2C1=PB10/PB11"是**错的**，也是 CubeMX 两次吞掉 I2C 配置的根因。改用**手写驱动** `Core/Src/i2c.c`（不经 CubeMX，重新生成不会被冲）；HAL 的 `stm32f1xx_hal_i2c.c/.h` 从 `C:\Users\asus\STM32Cube\Repository\STM32Cube_FW_F1_V1.8.7\` 手动拷进工程；`stm32f1xx_hal_conf.h` 手动放开 `HAL_I2C_MODULE_ENABLED`。
2. **直线提速**（他提的）：连续 1 秒 |误差|≤1 → 直道目标**斜坡升到 95**（每拍 +3，误差一大立刻回落）；遥测 `SB=1` 表示生效。
3. **葫芦弯相切点检测**（他的方案 + 实测数据修正）：判据 = **图案分裂成两组**（最左活跃与最右活跃之间空 ≥2 路）+ 锁存（一段分离只记 1 次）；累计 3 个相切点清零。**"翻转转向"默认关闭**（`GOURD_USE_FLIP 0`）——数据证明通用 PD 就正确进了下一个圆。遥测 `GW=` 显示计数。
   **实测指纹**（他截的 IR）：`00110011`(3,4+7,8) → `11000011`(1,2+7,8) → `00000011`(只剩右 2) → `00011000`(回到中间两路 = 进入下一个圆)；接近切点前**最外路先出现**。普通循迹时稳定在 `00011000/00011100`；十字是 `11111111`（一大片连着亮）——三种特征天然分得开。
4. **锁车问题修复**（据 `文档/锁车问题-调研与修改建议-20260922.md`）：根因 = `CAR_EMERGENCY` **没有任何退出路径** + 最可能的触发是**串口 RX(PA10) 悬空 + 电机 EMI 凑出假命令 `X`**（过弯大电流时最易中招）。已做：① 急停里**按住启动键 2 秒解除** ② 急停记录并打印原因（`STOP by KEY/SERIAL/OTHER`）③ **PA10 重配为输入+上拉** ④ 命令白名单 ⑤ **`X` 改双发 `XX`** ⑥ 修 `key.c` "上电即长按"隐患（`press_tick` 初值 0）+开机 300ms 不认按键。
5. **十字判据**加"宽图案持续时间"上限（≤6 拍=真十字直行；>6 拍=葫芦出口/直角入口 → 接着转）+ 修 `lost_cycles` uint8 回绕（丢线会真正停住）。
6. **GitHub 接好**：`https://github.com/xigua862/SMARTCAR`（公开）—— main + 标签 `fw-0922-1500`；队友直接 `git clone`。⚠️ **以后每次改固件前先 commit**（他要求"能回退"）。
7. 新车 v2 实测尺寸（我用 Python 解析 STL 量的）：板 **149.84 × 122.69 × 2.5mm**；电机支架孔 17×17 四角；PCB 可调长槽梯子（外列间距 85 ≈ PCB 的 83）；球脚轮法兰 2×φ3.2 **间距 42.3**；扩展板 72 × 40.12 × 2.0（固定槽距 65.4）。

### ⏳ 新对话接着做（按优先级）
1. **串口 RX 还不通**（TX 正常 ✗）→ **量"CH340 模块 TXD ↔ 板子 PA10"的通断**（必须 0Ω）→ 修好才能在线调参（`P/S/D/S` 现在全废）
2. **验证 MPU6050**（不需要 RX）：**手转车头看遥测 `GZ=`** 变不变（变 = I2C2 通了；一直 0 = 没认到）；修好 RX 后 `H` 指令的 `WHO=` 应为 **68**
3. **上车跑一次**：过葫芦看 `GW` 应 **1→2→0**（普通循迹时必须一直是 0）；再犯锁车 → 按住启动键 2 秒解除 + 把 `STOP by ...` 那行发出来
4. **灯（下午到）**：焊灯 —— 灯珠**长脚→板子端口、短脚→1k 电阻→GND**；**PC13 那颗用 4.7k**（该脚驱动弱）。焊完"读秒/运行/丢线/急停"灯效就能看图 ✓
5. 量两个数：**球脚轮静载**（秤顶前支撑，1kg 车 = 100~150g）、**传感器离地**（6~7mm）
6. ⚠️ **检录硬要求**：板上要有 **"2026 机器车循迹+队伍名"丝印** —— 一直没有结论，现场会卡检录，**尽早确认**
7. 后续：M4 速度闭环（标定 RPM ≈ 3.59 × PWM）/ M7 终点停车（图案 + 里程双条件）
8. 蜂鸣器：**仍不响**（他实测"没烧录的板子上电时出厂测试把它带响过"→ 电路/元件其实是好的；我上次"调试器强制输出"的测试无效，因为**F1 在调试暂停时定时器默认也停**）；已搁置

### 今天踩的新坑
- 用 python 批量改 C 源码时，**`\r\n`/`\0` 转义会被吃成真字节** → 编译报 "missing closing quote" / NUL warning → 改完**立刻编译验证**
- 提交了**一个编译不过的版本**（`init` 里漏改开关）→ 立刻修 + 再提交 ✓（git 的价值）

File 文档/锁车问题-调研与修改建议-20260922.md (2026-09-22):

# 锁车问题 · 调研结果与修改建议（2026-09-22）

> **给接手调试的 AI**：这是基于**通读整个工程**（`Core/App` 全部文件 + `文档/` + git 历史）后的结论。
> **请先读完本文再动代码。** 用户的明确要求：**改动前先说明改什么、为什么**；不要顺手改与本文无关的东西。
> 相关信息另见：`文档/待修与提醒-20260921.md`（其它已发现问题清单）、`文档/代码交接说明-20260921.md`（工程入门）。

---

## 一、症状（用户原话）

> "这车跑一段就停车跑一段就停车，特别是过复杂弯道的时候。"
> 后续补充：**"停了就是再怎么放都没反应"** —— 把车放回线上、挪动都没反应。

**关键点**：**不自动恢复** ↔ 这一句把范围缩到了很小。

---

## 二、已排除的可能（有代码依据）

| 候选 | 结论 | 依据 |
|---|---|---|
| 丢线兜底超时停车 | ❌ **排除** | `control/line_follow.c:153-168`：丢线超时确实会 `motor_stop()`，但**只要任一传感器重新看到线就立刻恢复**（`r.active != 0` → `lost_cycles = 0`）。与"再怎么放都没反应"矛盾 |
| `speed.c` 除零 | ❌ 排除 | `drivers/speed.c:35` 有 `if (dt == 0) dt = 1;` |
| 看门狗复位 | ❌ 排除 | 工程里没有启用 IWDG/WWDG |
| 电池/驱动过流保护 | ⚠️ **不是本次主因** | 那类保护**会自恢复**（负载一掉就恢复），与"没反应"矛盾。可作后续优化，但不是这个问题 |

---

## 三、结论：锁车 = `CAR_EMERGENCY`

**代码里唯一的"锁车"状态就是它，而且它没有任何自动退出路径。**

```c
/* fsm/car_fsm.c */
void car_fsm_request_start(void)
{
  if (state == CAR_IDLE || state == CAR_STOPPED) enter(CAR_COUNTDOWN);
}   /* ← 在 CAR_EMERGENCY 里调用它什么都不会发生 */
```

`CAR_EMERGENCY` 分支只做 `motor_stop()` + 三灯快闪，**没有回到其它状态的路径** →
**只能断电重上电**。`telemetry.c` 里急停命令的回复也写着"想再跑请重新上电"，即设计如此。

### 触发入口只有两个

| # | 入口 | 代码位置 |
|---|---|---|
| 1 | **长按启动键 1 秒** | `fsm/car_fsm.c` 的 `car_fsm_run()`：`if (key_take_long() && state != CAR_EMERGENCY) { car_fsm_emergency_stop(); return; }`（在 `#if !AUTO_START_ENABLE` 内；当前 `AUTO_START_ENABLE = 0`，即**按键是启用的**）|
| 2 | **串口收到 `X`** | `telemetry.c` 的 `X` 命令 → `car_fsm_emergency_stop()` |

### 两个入口都可能被"误触发"

1. **按键**：车在振动；按键被外壳/线材压住、或触点半接触 → `key.c` 消抖（稳定 10ms×3 = 30ms）后就认"按住" → 满 1s 即判长按。
   **另有一处隐患**：`key.c` 的 `key_init()` 里 `press_tick` 初值为 **0**，若**上电瞬间按键已处于按下（低电平）状态**，则 `HAL_GetTick() - 0 >= KEY_LONG_PRESS_MS(1000)` 会在**开机第一秒内**直接报一次长按 → 一起步就急停。
2. **串口**：`文档/代码交接说明-20260921.md` 的"已知问题"写着 **"串口 RX 收不到 → 待修"**。若 PA10 实际处于**悬空**状态，电机 EMI 很容易灌入凑出 `X` + `\r` 的组合 → 永久急停锁车。

---

## 四、判别流程（5 步，不用改代码，现场就能定案）

| 步骤 | 看什么 | 结论 |
|---|---|---|
| 1 | **三灯**：慢闪(250ms 节拍) = `CAR_STOPPED`；**快闪(150ms 节拍) = `CAR_EMERGENCY`**；第 3 灯常亮 = `CAR_RUN`；全灭 = `CAR_IDLE` | 快闪 → 就是急停锁车 |
| 2 | **串口还在不在打印** | 还在打 = MCU 活着；不打 = MCU 死机/复位（转 4）|
| 3 | 读遥测里的 **`ST=`**：0待机/1读秒/2运行/**3到站**/**4急停** | **`ST=4` = 定案（急停锁车）** |
| 4 | 串口日志里搜 **`OK EMERGENCY-STOP`** | 出现 = 是**串口 `X` 噪声**触发的（决定性证据）|
| 5 | 按一下启动键 / 断电重上电 | 按了没反应 + 重新上电恢复 = 确认 EMERGENCY 锁车 |

---

## 五、修改建议（按优先级）

### P0-1 ★ 给急停加"原因"并留出口
- **原因**：现在两个入口共用一条路，出了事分不清是按键还是串口——这次就卡在这。比赛现场"锁死不能动"比"误停"更致命。
- **建议**：
  1. 在 `car_fsm.c` 里加一个 `emg_cause` 字段（0=无 1=按键 2=串口 3=其它），`car_fsm_emergency_stop()` 增加一个入参或在调用点分别设置；
  2. 进急停时通过 `telemetry` 打一行带原因的日志（如 `STOP by KEY` / `STOP by X`）；
  3. **给 EMERGENCY 加退出路径**：**长按 2 秒**回 `CAR_IDLE`（推荐），或可选"N 秒后自动回 IDLE"。

### P0-2 ★ 修 `key.c` 上电即长按的隐患
- `key_init()` 的 `press_tick` 初值 0 → 上电时按键若已是低电平，开机 1s 内直接报长按。
- **建议**：`key_init()` 补 `press_tick = HAL_GetTick();`；并考虑**忽略开机前 300~500ms 内的按键电平**（防上电抖动）。

### P0-3 ★ 串口 `X` 加二次确认 + 治 PA10 悬空
- 一个能"远程把车锁死"的命令，误触发代价太高。
- **建议**：`X` 改成需连发两次（如 `XX`）或加参数（`X 1`）；同时**把 PA10 的悬空问题解决**（空脚配置上拉或下拉；`gpio.c`/CubeMX 里改），并在接收侧做白名单校验（只接受已知命令字母 + 长度上限，现在已有 32 字节上限，可再加首字母白名单）。

### P1-1 确认 RX 是否真的坏
- README 把串口命令表当可用功能写，交接说明写"RX 收不到"。**这两者矛盾**，请先确认现状（发 `V` 看有无回）。
- 若 RX 确实坏：**在线调参全废**（`P/S/D` 只能改宏重烧），优先级其实很高。

### P1-2 复现与回归测试（改完必须做）
1. **复现急停**：架空车，长按启动键 1s → 应进 EMERGENCY（三灯快闪、串口 `ST=4`、日志出现原因行）；
2. **验证新出口**：长按 2s → 应回 IDLE，且能再次按键启动；
3. **验证区分原因**：串口发 `X` → 日志应显示"by X"；
4. **回归丢线停车**：架空 + 挡住 8 路传感器 → 按设计约 1.5s（`LOST_MAX_CYCLES 150` × 10ms）后停车，**且此时把纸拿开、让传感器重见线，车应立即恢复**（这条是既有行为，别改坏）；
5. **回归按键启动**：短按 → 3s 读秒 → 起跑，正常。

---

## 六、别动的东西（边界）

- `app_config.h` 的 **`LINE_ACTIVE_LEVEL`**（本车 8 路模块"白线输出高"→ `GPIO_PIN_SET`，实测定的）、**`LINE_CHANNEL_TABLE` 引脚顺序**（左→右 `-7…+7`）
- **编码器配置**（TIM3=左/TIM4=右，`ENCODER_PPR 422` = 11×9.6×4 倍频）
- **`MOTOR_LEFT_INVERT` / `MOTOR_RIGHT_INVERT`**（正数=前进，实测定的）
- 改完请按项目规矩**更新 `FW_TAG`**（格式 `MMDD-HHMM`），方便用串口确认烧没烧

---

## 七、给接手者的"现场读日志"速查

```
FW:0922-0940 IR:10110000 RPM1=210 RPM2=205 KP=3.0 SP=70 ST=2 GZ=0 GW=0 SB=0
```
- `IR:` 8 位 = 从左到右 8 路（**第 1 个字符 = 最左那路**，`line_sensor.c:23` 用 `1u<<i`，i 跟通道表）
- `ST:` 0待机 / 1读秒 / 2运行 / 3到站 / 4急停
- `GZ` 偏航率(°/s，IMU)｜`GW` 葫芦相切点计数（跑完整圈应回到 3→0）｜`SB` 直线提速中标志
- 待机 500ms 一行；读秒/运行中 **50ms** 一行
- 串口命令：`P<KP>` `D<KD>` `S<速度>` `T<1|2><pwm>` `M<L><R>` `L<0~7>` `B[ms]` `R`(启动) `V`(版本) `H`(诊断) `X`(急停)

---

## 八、本次复查的其它发现（与锁车无关，但值得知道）

详见 `文档/待修与提醒-20260921.md` 的"2026-09-22 复查更新"一节，摘要：

| 项 | 要点 |
|---|---|
| 葫芦状态机可能误触发 | 判据"最外路亮→3 拍内扩散"在**直角弯/十字入口**同样成立；命中后 15 拍内丢线会**反向修正**。**用遥测 `GW` 验证**（跑完整圈应为 3→0，乱涨即误触发）；可用 IMU 的 `GZ` 符号翻转做闸门 |
| 魔数 `3` | `line_follow.c:136,182` 的 `-gourd_dir * 3` 未进 `app_config.h`，违反"唯一调参入口"约定，建议提成宏 |
| 直线提速瞬跳 | `sp = 99` 无斜坡，建议每拍 +2~3；99 是满 PWM，建议留余量（95） |
| 注释与实现不符 | `gourd_waves` 注释写"退出"，实现只是清零 |
| IMU 阻塞隐患 | `imu.c:49` 在 **10ms 节拍**里做阻塞式 I2C 读，超时 **50ms** → 线路接触不良时主循环会被拖慢（100Hz→20Hz 级）。判据：遥测行距是否还稳在 50ms |
| 检录硬要求 | 规则要求板上必须有 **"2026 机器车循迹+队伍名"丝印**；`代码方案-20260920.md` §五 Q6 问过但**未见结论**，现场会卡检录，请优先确认 |

---

*本文只做诊断与建议，未改动任何代码。*

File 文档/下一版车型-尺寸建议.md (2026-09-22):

# 下一版车型 · 尺寸建议（2026-09-20 调研后）

> 背景：现车是"等比复刻学长的车"——**总长 229mm、前瞻（传感中心→驱动轴）213mm、轴距（驱动轴→球脚轮）约 182mm、轮距 117mm**。
> 他实跑反馈："**车太长，多弯道过不去**"（直角弯/圆环切弯、丢线）。
> 本文是调研后的定量建议。**先看 §1 的结论表**。

---

## 1. 结论表（推荐值）

| 项目 | 现车 | **推荐（下一版）** | 关键依据 |
|---|---|---|---|
| **前瞻**（传感中心→驱动轴） | 213 mm | **100~120 mm（取 110）** | 弦切偏差 Δ≈d²/(2R)：213→**66mm**（2.6 条线宽，等于车头常年切进弯内 66mm）；110→**18mm**（0.7 条线宽）。下限由延迟定：d ≥ 2·v·t_r ≈ 70~120mm（v=1.2m/s，t_r≈30~50ms） |
| **轴距**（驱动轴→球脚轮） | ~182 mm | **120~140 mm（取 130）** | 对照官方三轮车模（整车 180~235mm、轮距 155~180、轮径 64）；四轮车模轴距 200/轮距 155。球脚轮是低摩擦球，轴距主要影响直线稳定性与配重，不是转弯瓶颈 |
| **轮距** | 117 mm | **120~130 mm** | 差速车内/外轮速比 =(R−b/2)/(R+b/2)：R=342 时 b=117→0.70（已经不错）；加宽到 125 提升抗侧翻（R342@1.2m/s 侧向 0.43g）。**别窄于 ~2×轮径** |
| **总长**（含传感支架） | 229 mm | **165~190 mm（取 ~175）** | 外廓扫掠 R_out=√((R+b/2)²+L_front²)：现状 R342 时前外角外扩 **+137mm**（必然压到相邻线）；新版 +90mm 上下。**外扩量必须小于赛道上相邻线段最小间距**（见 §4） |
| 传感条 | 90mm / 8 路（间距 12.9mm） | **保留**（间距 10~13mm 属合理区间） | 对标 Pololu QTR-8RC（8 路 / 9.53mm 间距 / 板 75×12.7） |
| 传感离地 | 10 mm | **5~8 mm** | 公开资料：3~8mm 为佳（过高易受环境光干扰、过低易刮擦） |

**一句话**：**把前悬砍掉一半**（前瞻 213→110），整车从 229 收到 ~175，轮距微加宽。收益：R342 里的内切外偏 66mm→18mm、外廓外扩 137→90mm、等效转向增益 Kp·d 降 1.9 倍（**KP 可以放大到约 2 倍**，车会更"听话"）。

---

## 2. 为什么"车长"是病根（三条判据）

1. **弦切外偏**：车沿半径 R 走、传感条在前方 d 处 → 传感条中心比轨迹**内切** Δ≈d²/(2R)。
   - d=213, R=342 → **66mm**（2.6 倍线宽！）→ 控制器常年"提前看到弯心"，出弯车尾甩外、压到另一条线
   - d=110 → 18mm；d=90 → 12mm
2. **外廓扫掠**：转弯时前外角半径 R_out=√((R+b/2)²+L_front²)，超出后轴轨迹的量在相切圆环/Ω 回头弯里会**压到相邻线**。现状 +137mm；新版 +90mm。
3. **等效转向增益**：e_传感 ≈ e_后轴 + d·θ → **等效微分增益 = Kp·d**。d 缩小后 KP 需要重新标定（可以更大）。

⚠️ 注意：差速车的**几何最小转弯半径 = 0**（可绕后轴原地转），所以"转不过弯"**不是**转弯半径不够，而是上面三条（传感器被甩到线外 + 车头车尾扫掠 + 反应慢）。

---

## 3. 布局建议（尽量复用现有件）

```
              ← 车头                                                  车尾 →
  ┌──────┬───────────┬──────────────┬────────────────────────┬──────┐
  │球脚轮│  传感条   │   驱动轴 0   │  电机×2 + 电池(压轴)   │降压模块│
  └──────┴───────────┴──────────────┴────────────────────────┴──────┘
     +130      +110          0            -10 ~ -35               -45
```
- **球脚轮**在传感条前方一点（保护传感条、支撑三角形不至于太小）；高度可调机构（铜柱+垫片）照用
- **PCB 90×70 不用重做**：抬高到 4cm 叠在电机/电池上方（孔距 X62×Y83 照用）
- **电池**压驱动轴（重心），预留 ±2cm 长条孔调重心（照旧）
- 后端留 40~50mm 给降压模块与接线
- 前支撑/传感支架**都做成可前后调的长条孔（±15~20mm）**，前瞻做成**两档（100 / 120mm）**——一次打样能试多种组合，这是最省返工的做法

---

## 4. ★ 你要先量一个数

**赛道图（或实地）上，相邻两条线的最小间距**（相切圆环切点附近、Ω 回头弯两条平行腿之间、小 S 两段之间）。
判据：**外廓外扩量 < 该间距**。例：若最小间距只有 100mm，那 L_front 要压到 ~130mm（即总长 ≈160）；若 150mm，则可放到 ~175。

---

## 5. 注意事项

- **轴距别缩到 <100mm**：重心偏前时球脚轮会承担过多重量 → 驱动轮抓地下降、直线稳定性变差
- 前瞻缩短后 **KP 必须重调**（等效增益变了，可放大 ~2 倍）；速度自适应阈值也要重设
- **最省事的验证路径**：先花几十块**切一块新的亚克力底板**（只改前悬：传感条+球脚轮整体内缩），把 PCB/电机/电池原样搬过去 → 实跑对比"短前瞻 vs 现在的 213mm"。**验证有效再谈整车重做**，别一上来重画一切
- 本文数字是**几何推导 + 同类车模对照**，没有权威公式，最终以实跑为准

---

## 6. 信息来源（调研记录）

- 官方车模规格（轮距/整车尺寸）：卓晴《第二十届全国大学生智能汽车竞赛车模平台》 https://blog.csdn.net/zhuoqingjoking97298/article/details/143962790
  - 博思威龙 F 型**三轮差速**：180×200×65、轮距 155、轮径 64；北京科宇 G 型三轮：235×208×64、轮距 180、轮径 64；四轮 NewB/C 型：轴距 200、轮距 155
- 竞速规则（30×25×20cm 外轮廓上限、禁改轴/轮间距）：https://blog.csdn.net/zhuoqingjoking97298/article/details/143673441
- 前瞻长度实测（40/45/50cm 都完赛，长度主要影响速度）：https://blog.csdn.net/zhuoqingjoking97298/article/details/110849251
- 差速转向运动模型（轮距/偏航角/转动惯量）：https://blog.csdn.net/zhuoqingjoking97298/article/details/146120519
- 传感器阵列间距对标：Pololu QTR-8RC https://www.pololu.com/product/961
- 传感安装高度 3~8mm：CSDN 文库《光电寻迹小车系统设计》
- ⚠️ 未找到："差速+灰度条前瞻应取 X mm"的权威原文；"轴距≤k×轮距"的经验公式（不存在可引用来源）；三轮车模的官方轴距（厂商只公布轮距）

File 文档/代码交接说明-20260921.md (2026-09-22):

# 智能车循迹 · 代码交接说明（2026-09-21）

> 面向：新加入的队友 / 未来的自己。
> 目标：**看完这份能编译、能烧录、能调参、知道哪里不能碰。**

---

## 1. 项目是什么

- **主控**：STM32F103C8T6（核心板插底板），HAL 库 + Keil MDK 工程
- **驱动**：TB6612 双路电机驱动 → 2× JGA25-370 减速电机（差速转向）
- **循迹**：8 路灰度/红外模块（数字量，装在车头前伸的扩展板上，**前瞻可调**）
- **测速**：编码器正交解码（左 TIM3 / 右 TIM4）
- **底盘**：三轮三点（后两轮驱动 + 前球脚轮），3D 打印底板
- **比赛**：5m×5m 场地，**黑底 + 25mm 白线**，含直角弯/十字/Ω 回头弯/相切圆环；到点积分制（到 G 点 100 分），**每队发车 2 次**

---

## 2. 目录结构

```
代码/
├── Core/
│   ├── Src/  Inc/          ← CubeMX 生成的（main/gpio/tim/usart/it/msp）★ 只改 USER CODE 区
│   └── App/                ← 我们自己写的分层框架
│       ├── app_config.h    ← ★★ 唯一调参入口（参数/开关/引脚表/版本号）
│       ├── app.c/.h        ← 顶层调度（10ms 控制节拍 + 10ms 人机节拍 + 遥测节拍）
│       ├── telemetry.c/.h  ← 串口遥测 + 在线调参（寄存器级中断收命令，防 HAL 卡死）
│       ├── drivers/        ← 硬件抽象层
│       │   ├── motor.c        TB6612 双电机 + 方向映射
│       │   ├── line_sensor.c  8 路加权误差
│       │   ├── speed.c        测速（编码器）
│       │   ├── encoder.c      正交解码
│       │   ├── led.c          三灯（PC13/PB14/PB15，高电平点亮）
│       │   ├── buzzer.c       PA11 PWM 蜂鸣器（非阻塞）
│       │   ├── key.c          启动键（消抖 + 短按/长按）
│       │   └── imu.c          MPU6050（预留，未启用）
│       ├── control/        ← 控制层
│       │   ├── pid.c          通用 PID（抗饱和/微分先行）
│       │   ├── filter.c       一阶低通
│       │   └── line_follow.c  ★核心：PD 差速 + 速度自适应 + 丢线旋转 + 十字强制直行
│       └── fsm/car_fsm.c   ← 状态机：IDLE→按键→COUNTDOWN(3s读秒)→RUN→STOPPED/EMERGENCY
├── Drivers/                ← ST 官方 HAL + CMSIS（别动）
└── MDK-ARM/                ← Keil 工程 test16.uvprojx
```

**分层原则**：`app_config.h` 管参数与开关 → `drivers/` 管硬件 → `control/` 管算法 → `fsm/` 管流程 → `telemetry` 是唯一对外接口。

---

## 3. 编译与烧录

**Keil**：打开 `MDK-ARM/test16.uvprojx` → `F7` 编译 → `F8` 下载（ST-Link：SWDIO=PA13、SWCLK=PA14、GND；**3.3V 可接但要与车电源共地**）

**命令行编译**（CI/脚本用）：
```
UV4.exe -b "MDK-ARM\test16.uvprojx" -o "MDK-ARM\build.log"
```

**OpenOCD 烧录**（无需开 Keil）：
```
openocd -f interface/stlink.cfg -c "transport select swd" -f target/stm32f1x.cfg ^
        -c "adapter speed 500" -c "program MDK-ARM/test16/test16.hex verify reset exit"
```

**CubeMX 工程**：`test16.ioc`（在根目录），改引脚/外设用它重新生成。

---

## 4. 硬件对应（引脚表）

| 功能 | 引脚 |
|---|---|
| 电机 PWM | PA2 / PA3（TIM2_CH3 / CH4） |
| 电机方向 | PA4 / PA5（左）、PB3 / PB4（右） |
| 编码器 | 左 PA6/PA7（TIM3）、右 PB6/PB7（TIM4） |
| 8 路循迹 | PA0, PA1, PA8, PA15, PB0, PB1, PB12, PB13（**左→右**） |
| 串口 / 蓝牙 | PA9(TX) / PA10(RX)，115200 |
| LED×3 | PC13 / PB14 / PB15（**高电平点亮**） |
| 启动键 | PB9（按下接地，内部上拉） |
| 蜂鸣器 | PA11（TIM1_CH4 PWM，2.7kHz） |
| SWD | PA13 / PA14 |

详细接线见同包内 `接线对照表.html`。

---

## 5. 串口命令表（115200，**每条命令必须以 `\r\n` 结尾**）

| 命令 | 作用 |
|---|---|
| `P 3.0` | 设 KP（内部放大 10 倍存，范围 0.5~50） |
| `D 0.5` | 设 KD（0~20） |
| `S 60` | 设**直道**速度（弯道自动 = ×0.7） |
| `T 1 40` / `T 2 40` | 单电机测试（**正数 = 前进**）；`T 0 0` 停 |
| `M 40 40` | 直接给左右轮 PWM（进测试模式，`T 0 0` 退出） |
| `L 0~7` | 直接点灯（bit0=LED1、bit1=LED2、bit2=LED3） |
| `B [ms]` | 蜂鸣器响（默认 500ms） |
| `R` | 串口启动（等效按启动键：读秒→跑） |
| `V` | 打印版本横幅 |
| `H` | 诊断：8 路原始位图 + 误差 + 按键 + 编码器计数 |
| `X` | **急停** |

**遥测行**（待机 500ms 一行 / 读秒与运行中 50ms 一行）：
```
FW:0921-2135 IR:10110000 RPM1=210 RPM2=205 KP=3.0 KD=0.0 SP=60 ST=2
```
`ST`：**0=待机 1=读秒 2=运行 3=到站停车 4=急停**

---

## 6. 调参入口（**只在 `Core/App/app_config.h`**）

| 类别 | 参数 |
|---|---|
| 功能开关 | `USE_ENCODER`（编码器测速）、`USE_IMU`、`USE_SPEED_LOOP`（速度闭环）、`USE_ADAPTIVE_SPEED`（速度自适应）、`USE_D_FILTER`、`AUTO_START_ENABLE`（1=上电自动跑，调试用） |
| 循迹 | `KP` / `KD`（放大 10 倍）、`BASE_SPEED`、`SPEED_STRAIGHT` / `SPEED_CURVE`、`CURVE_ABS_ERR_THRESH` |
| 丢线 | `LOST_SPIN_DELAY` / `LOST_SPIN_SPEED` / `LOST_MAX_CYCLES` |
| 十字 | `CROSS_ACTIVE_MIN`（同时 ≥N 路触发 → 强制直行）、`CROSS_CONFIRM_CNT` |
| **极性** | `LINE_ACTIVE_LEVEL`（本车 8 路模块 = **白线输出高** → `GPIO_PIN_SET`） |
| 电机方向 | `MOTOR_LEFT_INVERT` / `MOTOR_RIGHT_INVERT`（正数=前进；反了就改这里，别改线） |
| 编码器 | `ENCODER_PPR = 422`（= 11 × 9.6 × 4 倍频） |
| 版本 | `FW_TAG`（改完代码更新，串口每行都带 → 一眼确认烧没烧） |

---

## 7. ⚠️ 必须知道的坑（都是踩过的）

1. **CubeMX 重新生成后必查三处**：
   - `Core/Src/usart.c` 的 `USER CODE BEGIN USART1_Init 1` 里必须有 4 行（WordLength/StopBits/Parity/Mode）——**6.17 版本生成时会吞掉**，导致 `Mode=0` → 串口**收发全废**（现象：TX 能发？不，两边都不通）
   - `Core/Src/main.c` 的 `#include "app.h"` **必须在 `USER CODE BEGIN Includes` 区**里（否则被冲掉 → 编译警告）
   - `.ioc` 里编码器枚举要写 `TIM_ENCODERMODE_TI12`（写成 `EncoderMode_TI12` 编译不过）
2. **`motor.c` 必须 `#include "app_config.h"`**（否则 `#if MOTOR_LEFT_INVERT` 被当成 0 → **方向反转静默失效**；已在文件里加 `#error` 守卫）
3. **接线安全**：8 路模块若供 5V，其 DO 可能是 5V 电平 → **PA0/PA1/PB0/PB1 不耐 5V**，必须先量（本模块实测可直连）
4. **地环路**：烧录和调参别同时插两条 USB（ST-Link + 串口），两个地会打架 → 串口收不到。**一次只插一条**
5. **电池没电 = 电机嗡嗡转不动**（不是代码问题，先量 VM 电压）
6. **`EXTI15_10_IRQHandler` 已删除**（新车不用霍尔）

---

## 8. 已知问题 / 待办

| 项 | 状态 |
|---|---|
| 蜂鸣器不响 | **硬件问题**（芯片侧已验证输出正常，问题在驱动电路/元件）；状态指示目前靠 LED + 串口 |
| 串口 RX 收不到 | 待修（TX 正常；怀疑"模块 TXD → PA10"那根线） |
| 终点检测（到 G 点停车） | **未实现**（故意留到最后做，要先用实车测"斑马线图案"） |
| 速度闭环 | 未启用（`USE_SPEED_LOOP=0`）；已有标定：**RPM ≈ 3.59 × PWM**（满 PWM ≈ 355rpm ≈ 1.23m/s） |
| 十字 | 已有逻辑（多路触发 → 强制直行） |
| 葫芦弯/圆环 | 靠丢线恢复 + 速度自适应，未专门调 |
| MPU6050 | 未启用（I2C 还没在 CubeMX 里配） |

---

## 9. 最近一次改动（2026-09-21）

- 新车 v2（3D 打印底板）装车：**板长 149.84 × 宽 122.69 × 厚 2.5mm**，传感器距驱动轴 **124mm**（另配可调扩展板）
- 固件 `FW:0921-2135`：**KP 由 2.0 提到 3.0**（前瞻 213→124mm，等效增益 ×1.72）、直道速度 60 / 弯道 42
- 电机方向反转宏、8 路极性（白线出高）、RPM 计算按真实窗口修正

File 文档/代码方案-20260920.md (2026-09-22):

# 代码方案（待批）—— 2026-09-20

> **✅ 进度（2026-09-20 晚）**：他已批（6 问全答：8 路可直连 / 终点最后写 / 读秒保留可配 / 只有串口+按键消抖要写 / 蜂鸣器 2.7k 先试 / 丝印待核）。
> **M1 + M2 已做完**：CubeMX 重配重新生成 ✓、三个新驱动（led/buzzer/key）✓、状态机（读秒启动链）✓、旧坑修补 ✓、**Keil 编译 0 错 0 警** ✓。
> 新增/改动：权重表改 **-7…+7**（他提的）、KP=2/KD=0、PPR=422、USE_ENCODER=1（只读测速）。
> **下一步 = 他烧录验证 M1**（见 §七 M1 的验收），通过后进 M3（落地慢速循迹）。
> ⚠️ CubeMX 把 I2C1 丢了 → MPU6050 留到启用时再补配（不影响现在）。

> **状态**：车已装完 + 上电成功。这份文件 = **功能清单 + 思路 + 代码框架 + 里程碑**。
> **请你先看 §五 的 6 个待定问题**，批完我就正式开工（开工前不会再动任何东西）。

---

## 一、比赛规则里跟代码有关的事实（已从 `文档/5.机器车循迹比赛规则.pdf` 提取）

| 项 | 规则 | 对代码的要求 |
|---|---|---|
| 赛道 | 5m×5m 场地，**黑底 + 25mm 白线**（单线循迹） | **极性跟我们旧车相反**（旧车白底黑线）→ `LINE_ACTIVE_LEVEL` 必须上车实测确认（M1 做） |
| 赛道元素 | 小 S 弯 / 大 S 弯 / **3 个直角弯** / **2 个十字** / **2 个 Ω 回头弯** / **4 个相切圆环** | 十字要有专门逻辑（不能乱修）；Ω / 圆环靠"丢线恢复 + 大误差强修正" |
| 起终点 | **S、G 是两条斑马线，相距 400mm**，都在顶边中央；车在两条斑马线**中间**发车 | 终点检测 ≈ 识别"斑马线图案"（跟十字区分开，见 §四） |
| 路线 | S→G **一趟**（不是绕圈）；**每队发车 2 次**，积分取平均 | **停车后要能原地重新启动第二次**（按键重启，不用断电） |
| 停车合格 | 车尾过 G 斑马线左端、**车头（含传感器）不超过 S 斑马线右端** → 整车停在 400mm 区间内 | 终点判定后**立即急停**（冲过头就压 S 线 → 不合格） |
| 计分 | 到点 A10/B25/C40/D50/E75/F90/**G100**；到 G 不停车 **-5**；偏线终止 | 稳 > 快：先保证到 G 停住，再提速 |
| 计时 | 裁判发令起算，**15 分钟内完成 2 次发车** | 我们的"3s 读秒"会白耗 3s（见 §五 Q3） |
| 无线 | **禁止远程遥控**（含蓝牙遥控）；但允许现场改程序 | 蓝牙**只用于调参/看数据**，绝不做遥控行驶 |
| 尺寸 | 投影宽 ≤ 30cm（我们 ~15.7cm ✓）| 无影响 |
| ⚠️ 检录 | 电路板（主控/驱动/传感器任选其一）必须有 **"2026 机器车循迹+队伍名"丝印 logo** | ★ **你的板子上有没有这个丝印？** 没有的话检录可能卡（见 §五 Q6） |

---

## 二、现在的软件是什么状态（我已逐文件核对）

| 文件 | 状态 |
|---|---|
| `Core/App/app_config.h` | ✅ 已是 8 路版（8 通道权重表）——但**引脚在 CubeMX 里根本没配** |
| `Core/App/drivers/motor.c` | ✅ 双电机 PWM + 方向（含旧车"右轮方向对调"修复），新车**需实测左右/正反** |
| `Core/App/drivers/line_sensor.c` | ✅ 加权误差 + active 计数（PIN 表驱动，改 8 路只改 app_config） |
| `Core/App/drivers/speed.c` | ⚠️ 一半：霍尔分支新车作废；编码器分支在（需 CubeMX 配 TIM3/TIM4） |
| `Core/App/drivers/encoder.c` | ⚠️ 指向 `htim3/htim4`（CubeMX 配好即通）；**PPR 要按四倍频改** |
| `Core/App/control/line_follow.c` | ✅ PD + 速度自适应 + 丢线旋转都写了；❌ 速度环 `pid_init(0,0,0)` **是空壳** |
| `Core/App/fsm/car_fsm.c` | ❌ 只有骨架：**没有读秒、没有终点检测**；默认直接循迹 |
| `Core/App/telemetry.c` | ⚠️ 命令能用，但 `H` 指令读的是**已退役的霍尔引脚**（会编译不过） |
| LED / 蜂鸣器 / 按键 | ❌ **完全没写**（引脚也没在 CubeMX 配） |
| CubeMX 配置 | ❌ 还是旧 5 路 + 霍尔 EXTI：**烧进去 8 路是坏的**（这就是"必须重配"的原因） |

**旧车已验证、可以照抄的经验**：转向映射（电机1=左轮）、串口命令集 `P/S/D/T/H`、`tune.ps1` 调参流程、
10ms 控制周期、丢线"先保持方向再原地转"策略、以及两个坑（电池没电=电机嗡嗡不转、串口 ORE 溢出要读 DR 自清）。
**必须重调的**：KP（前瞻 5cm→21.3cm，几何增益约 ×4.3 → 旧车 KP=10 只能当上限，**起步试 2~3**）。

---

## 三、功能清单（做完这辆车就齐了）

### A. 启动与人机（全新）
- A1 上电 → `IDLE`：三灯灭、电机停、蜂鸣器不响（防上电乱响，硬件 10k 下拉已做）
- A2 按启动键 → **3s 读秒**：LED1→LED2→LED3 逐个亮（各 1s）+ 每亮一下蜂鸣器"哔"一声
- A3 读秒完 → `RUN`：LED3 常亮 = 循迹中
- A4 **停车后可再按按键重新读秒发车**（比赛要发 2 次）
- A5 状态指示：丢线 → LED2 闪 + 短鸣；到终点 → 三灯闪 + 长鸣 2 声
- A6 长按按键 1s = **急停**（调车时用，比赛不碰车）

### B. 循迹控制（主体，已有骨架要修）
- B1 8 路加权误差（左负右正，-4…+4）
- B2 PD 差速：`corr = KP·e + KD·Δe`，`左轮 = base+corr / 右轮 = base-corr`（已实测过方向）
- B3 速度自适应：直道快 / 弯道慢（按 |e| 阈值）
- B4 D 项低通滤波（已有，压摆头）
- B5 丢线：先按原方向强修 2 个周期 → 仍丢线就原地转找线 → 转 N 圈找不到就停车（防跑飞）

### C. 赛道元素与终点（全新，本方案的重点）
- C1 **十字**：多路同时触发 → 强制直行不转向（等对称触发再退出）
- C2 **Ω / 圆环**：靠 B5 丢线恢复 + 大误差强修正（先跑通再优化）
- C3 **终点**：识别"斑马线图案" → 急停 + 长鸣（判定参数**要用实测数据定**，见 §四）

### D. 测速与闭环（编码器已装）
- D1 编码器读数（TIM3=左 / TIM4=右，四倍频）
- D2 500ms 窗口 RPM（已有）
- D3 速度闭环（PI）：先开环跑顺，再开闭环（**默认关，跑稳了再开**）
- D4 PWM↔RPM 标定系数（闭环必需，M4 实测两句数据填进去）

### E. 调参与遥测（沿用旧车习惯）
- E1 串口/蓝牙命令：`P <KP>` / `D <KD>` / `S <速度>` / `T <1|2> <pwm>`（单电机架空测）/ `H`（诊断）
- E2 修 **S 指令被自适应覆盖**的坑：改成 `S` 同时定"直道速度"，弯道速度 = 直道 × 比例
- E3 打印行保持旧格式（`IR:xxxxxxxx RPM1=.. RPM2=.. KP=.. KD=.. SP=..`）+ 追加状态字，`tune.ps1` 继续可用
- E4 `H` 指令改语义：打印 **8 路原始电平 + 按键 + 编码器计数**（旧车读霍尔 PA11/12，引脚已退役）

### F. 安全与兜底
- F1 丢线超时停车（已有逻辑，参数复核）
- F2 急停（按键长按）
- F3 所有"可能跑飞"的路径都收口到 `motor_stop()`

---

## 四、思路（关键设计）

### 4.1 状态机（car_fsm 重写）

```
       上电
        ↓
     [IDLE] ──按键──→ [COUNTDOWN 3s: LED1/2/3 + 哔] ──→ [RUN 循迹]
        ↑                                                    │
        │                                               到终点/丢线超时/急停
        └──────────── 按键重启 ←── [FINISH/STOP] ←───────────┘
```

### 4.2 十字怎么判（不靠猜，靠对称性）
- 8 路全亮/大半亮时，当前权重表 `-4…+4` 的和 **天然 = 0** → 只要"多路同时触发"就**直接强制 e=0（直行）**，不做转向。
- 判据：`active ≥ CROSS_ACTIVE_MIN`（初值 5~6）**连续 2~3 帧**才算十字（防单帧毛刺）。
- 好处：十字处不乱修，出去后传感器恢复少数几路亮 → 自动回到正常循迹。

### 4.3 终点怎么判（本方案唯一"要拿数据定"的地方）
- 难点：**终点斑马线 vs 十字**，两者都是"多路触发"，不能靠一路全亮就停车（第一个十字就会误停）。
- 区分思路（**先用实测数据验证再写**）：
  - 斑马线是**垂直于主线的短线段**（50mm 等间距分布在主线两侧）→ 扫过去的图案是"**断续/边缘先亮**"
  - 十字是**两条线交叉** → 图案是"**中间连续 + 两侧同时**"
  - 再加**里程条件**：编码器/时间跑够一段（终点在赛道最后）→ 双条件同时满足才急停
- ★ **落地办法**：M5 先用 A3 纸打印三种图案（斑马线 / 十字 / 普通线），把车架起来**手推过去**，串口把 8 路原始位图打出来 → 拿到真实图案再定参数。**不拍脑袋写判定。**

### 4.4 参数初值（都在 `app_config.h`，在线可改）

| 参数 | 初值 | 依据 |
|---|---|---|
| KP | **2~3**（kp_x10=20~30） | 前瞻 213mm，几何增益约 ×4.3；旧车 10 |
| KD | **0 起步** → 摆头再试 0.5~1.5 | 旧车 3.0，先纯 P 跑通 |
| 直道速度 | **35~45** | 旧车 SP=40 稳 |
| 弯道速度 | 直道 × 0.7 | 先保守 |
| 控制周期 | 10ms | 已有 |
| 丢线：强修 2 帧 / 转 35 / 上限 150 帧 | 复核 | 旧车经验 |
| 编码器 PPR | **422** | = 11 × 9.6 × **4（TI12 四倍频）**；装好**手转一圈核对** |
| 速度环 Kp/Ki | 0（先关） | M4 标定后填 |

---

## 五、★要你拍板的 6 件事

1. **8 路模块现在 VCC 接的哪儿？**（5V 还是 3.3V）
   —— 这是**唯一能烧单片机**的点：PA0/PA1/PB0/PB1 不耐 5V。
   如果你接的是 5V：请**先别接模块**，用万用表量一下模块 DO 输出高电平是多少伏（≤3.3V 才敢直连；是 5V 就得改 3.3V 供电或加电平转换）。
2. **终点判定用"图案 + 里程"双条件**（见 4.3），且判定参数**等 M5 实测数据出来再定** —— 同意吗？
3. **3s 读秒保留还是缩短？** 比赛计时从裁判发令开始，读秒会白耗 3s（到点积分不受影响，只影响"同分比时间"）。
   建议：**保留但做成可改参数**（`START_COUNTDOWN_MS`），比赛当天想缩成 1~2s 改一个数就行。
4. **蓝牙定位**：只做调参/看数据，**不做遥控行驶**（规则禁止遥控）——确认。
5. **蜂鸣器频率**：先按板上原来的 **2.7kHz** 试，不响/发闷就改 4kHz（改 `Period` 一个数）——认同这个顺序吗？
6. **丝印 logo**：你的板子上有 "2026 机器车循迹+队伍名" 丝印吗？没有的话我们得想个合规办法（贴标/下一版加印）。

---

## 六、代码框架（文件级）

### 6.1 新增文件
| 文件 | 职责 |
|---|---|
| `Core/App/drivers/led.c/.h` | 3 灯控制（**高电平点亮**）；`led_set(id,on)` / `led_all_off()` / 闪灯助手 |
| `Core/App/drivers/buzzer.c/.h` | PA11 TIM1_CH4 PWM：`buzzer_on(freq)` / `buzzer_off()` / `buzzer_beep(ms,times)`（非阻塞计数） |
| `Core/App/drivers/key.c/.h` | PB9 按键：10ms 轮询 + 消抖（稳定 30ms），短按/长按(1s) 事件 |

### 6.2 修改文件
| 文件 | 改什么 |
|---|---|
| `Core/App/app_config.h` | 加 LED/蜂鸣器/按键参数、`START_COUNTDOWN_MS`、十字阈值、速度环系数；KP 初值改 2~3 |
| `Core/App/fsm/car_fsm.c` | **重写**：IDLE/COUNTDOWN/RUN/FINISH/EMERGENCY + 终点判定挂载点（4.1 状态机） |
| `Core/App/control/line_follow.c` | 加十字强制直行；`S 指令` 速度同步；速度环 PID 参数占位 |
| `Core/App/telemetry.c` | `H` 改读 8 路+按键；打印加状态字；`S` 语义调整 |
| `Core/App/drivers/speed.c` | 删霍尔分支（新车无霍尔），编码器分支核对 |
| `Core/App/drivers/encoder.c` | 注释/PPR 修正（四倍频） |
| `Core/Inc/main.h` / `Core/Src/gpio.c` / `tim.c` / 新增 `i2c.c` | **由 CubeMX 重新生成**（配置见 6.3） |
| `MDK-ARM/test16.uvprojx` | 加新文件（led/buzzer/key）+ 补 `stm32f1xx_hal_i2c.c` |

### 6.3 CubeMX 要配成（这是"烧进去能用"的前提）

| 功能 | 引脚 | 模式 | 参数 |
|---|---|---|---|
| 8 路循迹 | PA0/PA1/PA8/PA15/PB0/PB1/PB12/PB13 | GPIO_Input | NOPULL，标签 LINE_1..8（**PA15 要关 JTAG**，已配好机制） |
| 左编码器 | PA6/PA7 | TIM3 Encoder | TI12，Prescaler 0，Period 65535 |
| 右编码器 | PB6/PB7 | TIM4 Encoder | TI12，Prescaler 0，Period 65535 |
| MPU6050 | PB10/PB11 | I2C1 | 400kHz（先配好，`USE_IMU=0` 不启用） |
| 蜂鸣器 | PA11 | TIM1_CH4 PWM | Prescaler 71、**Period 369 = 2.7kHz**（改 249 = 4kHz），Pulse 50% |
| 启动键 | PB9 | GPIO_Input | **PULLUP**（按下=低） |
| LED×3 | PC13/PB14/PB15 | GPIO_Output PP | 初始低（灭）；**高电平点亮** |
| 电机 | PA2/PA3(PWM) PA4/PA5/PB3/PB4(DIR) | 保持 | 不变 |
| 串口/SWD | PA9/PA10、PA13/PA14 | 保持 | 不变（PA10 的手工修复要回填） |
| 退役 | PA11/PA12 霍尔 EXTI、PB5 | 删除 | 霍尔测速不再用 |

---

## 七、里程碑（每步都能单独验证，不用等全部写完）

| # | 内容 | 你要做的事 | 验收标准 |
|---|---|---|---|
| **M1** | CubeMX 重配 + 重新生成 + 编译 0 错0警 + 新驱动骨架 | **车架空**、串口连电脑 | 串口打印 8 路原始电平；手挡每路传感器位图跟着变；按键按下有反应；三灯能点亮 |
| **M2** | 人机：按键 → 3s 读秒（灯 + 哔）→ 起跑 | 车架空 | 读秒节奏正确，蜂鸣器响得对 |
| **M3** | 循迹开环（8 路 PD + 自适应 + 丢线） | 车架空 → 落地慢速（SP≈35、KP≈2~3） | 架空：轮子转向/差速方向对；落地：能跟着线走不摆头 |
| **M4** | 编码器 + PWM↔RPM 标定 → 开速度环 | 手转轮子核对 PPR；跑两句测速度 | 手转一圈计数值 ≈ 422；开环/闭环速度一致 |
| **M5** | 十字 + 终点（**先测图案再写判定**） | 打印 A3 图案（斑马线/十字）铺地上，手推车扫过 | 串口能区分"十字/斑马线/普通线"三种图案 |
| **M6** | 调参冲速度 + 记数据（**CSDN 素材**） | 陪跑记录现象 | 完整 S→G 跑通 + 到 G 停住 |

---

## 八、风险与兜底

| 风险 | 后果 | 兜底 |
|---|---|---|
| 8 路模块 5V 直连 | **烧 PA0/PA1/PB0/PB1** | §五 Q1 先量电平/改 3.3V；不行就加电平转换 |
| CubeMX 重新生成冲掉手工改动 | 编译不过/工程文件丢 App 组 | 生成前**全量备份**（.ioc/生成代码/uvprojx），生成后比对 + 回填 PA10 修复 + Keil 编译核验 |
| 极性/权向试错 | 车往反方向跑 | M1 用串口位图 + 手推验证；`LINE_ACTIVE_LEVEL` 与权重表都在 app_config 一处可改 |
| 前瞻 213mm 增益高 | 摆头/画龙 | KP 从 2 起步，先慢后快；备好 D 项 + 低通 |
| 终点误判（第一个十字就停） | 直接丢分 | 双条件判定 + 实测图案 + "里程未到不停" |
| 丝印 logo 缺失 | 检录可能被卡 | §五 Q6，早发现早补 |

---

*批完这份我就按 M1 开工。中途每一步我都会先给你"现象 + 数据"再往下走。*

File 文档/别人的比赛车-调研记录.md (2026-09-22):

# 别人的比赛用车长什么样 · 调研记录（2026-09-20）

> 起因：他实跑后觉得自己的设计矛盾——"多弯道该用短车，我的车又长又加 IMU 又低趴；短车重心不稳才加加速模块，长车注意速度不需要；低趴需要吗？"
> 本文 = 调研结论 + 实车案例 + 来源链接。**全部数字都有出处或标注为推导。**

---

## 0. 结论速览

| 他的疑问 | 判定 | 依据 |
|---|---|---|
| "多弯道只需要短车" | ✅ **方向对**（短车 + 低重心 + 差速是多弯赛道标准解）；但**不是越短越好** | 龙邱缩微电磁手册原话（见 §2）；厂商同时提醒"短=容错率高、大=性能上限高"要权衡 |
| "短车重心不稳所以要加 IMU" | ❌ **因果关系是错的** | 差速车航向漂移率 = Δv/(B·v)，**只跟左右失配和轮距有关，与轴距无关**（§3 推导） |
| "长车注意速度就不需要 IMU" | ❌ **没有依据**（长车稳态漂移率与短车相同） | 同上 |
| "低趴需要吗" | ✅ **需要，但不是为了防翻**（防翻余量 2.7 倍）；真正理由是**减少左右轮载荷转移、保住内侧驱动轮抓地力** | §2 定量计算 + 龙邱/卓晴多篇 |

---

## 1. 实车案例（都实际打开过页面）

| # | 来源 | 车型 | 尺寸/轮距 | 离地/重心 | 传感器 | IMU 用途 |
|---|---|---|---|---|---|---|
| 1 | [卓晴·第20届车模平台](https://blog.csdn.net/zhuoqingjoking97298/article/details/143962790) | **G 型三轮（后两轮差速+前万向轮，就是我们的构型）** | 23.5×20.8×6.4 cm，**轮距 18cm**，轮径 6.4 | 前万向轮"减震软硬可调、阻尼小" | — | — |
| 2 | 同上（四轮 NewB/B 型） | 四轮阿克曼 | 28.5×17.8×6.0，轮距 15.5，**轴距 20cm** | **B 型公布离地间隙 0.75/1.65cm 两档**（全网少见的官方离地数据） | — | — |
| 3 | 同上（规则原文） | — | — | — | — | **官方赛"轮间距、轴间距不允许更改"**——轴距不是能调的变量 |
| 4 | [F 车模国一（十八届摄像头三轮）](https://blog.csdn.net/c18607/article/details/133071225) | 三轮差速 | — | **"电池后置并尽可能贴近地面，使车模重心后置"** | 摄像头 | **ICM20602 六轴；陀螺仪 Z 轴角速度作"抑制参数"**，配合模糊 PD |
| 5 | [20届双车跟随组三轮车模](https://blog.csdn.net/winf_feng/article/details/161752427) | 三轮（实验室跑到 3.5 m/s） | — | **BMI270 装在车模正中心**；PCB 四角嵌**飞控减震橡胶垫**；负压横梁略超前轮轴；建议电池背车尾 | 摄像头 | BMI270（**减震是为了保护 IMU**，高频振动会污染陀螺仪） |
| 6 | [令对手赞叹的车模（天大 负压电磁）](https://blog.csdn.net/zhuoqingjoking97298/article/details/131819675) | 舵机三轮+机械差速 | — | **矢量负压风扇**："转弯时拉动外侧风扇向外倾斜，产生向内的风力**抵消离心力**" | 电磁 | 未提 |
| 7 | [大连海事 双车接力技术报告](https://blog.csdn.net/zhuoqingjoking97298/article/details/120046109) | 三轮 | 规程：**长<300、宽<250、高<200 mm** | 电池+主板**装车尾增加尾部重力**；直立车重心贴近轮轴 | 摄像头+电磁 | **"两电机差速、陀螺仪回值 PID 拟合控制转向"**；直立车"陀螺仪 Z 角速度作 D 输入，**增加转向阻尼、减少震荡**" |
| 8 | [20届总决赛 缩微光电采访](https://blog.csdn.net/zhuoqingjoking97298/article/details/152023892) | 缩微光电自制（5 支国赛队） | 整车宽 15~20cm | 山大："光电管**重心比较低**、重量轻…**重心低能提高速度上限**" | 光电管/摄像头 | 山大："**写了惯导**，低速下完成各元素识别"；乐山师范："**陀螺仪+CCD 融合**处理断路" |
| 9 | [龙邱·缩微光电方案](https://blog.csdn.net/longqiu_lq/article/details/146426327) | 自制差速 | 电池夹在两电机中间 | **"底盘离地只有 0.4cm，已做到最低。底盘降低可有效降低重心、提升行驶稳定性、减少高速过弯侧翻风险"** | 摄像头 260fps/光电管 | 陀螺仪：①转向环串级 ②角度环闭环 ③**积分角度作为环岛进出判据** |
| 10 | [龙邱·缩微电磁方案](https://blog.csdn.net/longqiu_lq/article/details/146420325) | 差速四轮 | 整车宽 18.8cm | **"重心集中于转向中心附近、尽可能降低重心、减轻重量"** | 电磁 | 未强调 |

**一句话**：头部队伍的车都是"**短、低、轻、差速**"，重物的处理方式是**电池贴地/塞进两电机之间/后置**，IMU 普遍只用来做**转向阻尼 + 环岛积分 + 断路惯导**，没人用配重块或风阻罩。

---

## 2. 低趴：需要，但不是为了防翻

**侧翻阈值**：侧向加速度 > (轮距/2)/重心高 · g 才翻车。
以我们的车（轮距 117mm、重心高估 50mm、过 R342 @1.2m/s）：

| 项 | 数值 |
|---|---|
| 过弯侧向加速度 | v²/R = **0.43 g** |
| 侧翻阈值 | (0.117/2)/0.05 = **1.17 g** |
| **安全余量** | **2.73 倍** |
| 先滑还是先翻 | 摩擦极限(μ≈0.8)对应重心高 73mm；我们 50mm < 73mm → **先打滑，永远不翻** |

→ **低趴在这条赛道上完全不是防翻措施。**

**低趴真正的收益 = 减少左右轮载荷转移** ΔN = m·a·h/B（占比与质量无关）：
- 重心 50mm → 转移 **18.3%**；30mm → **11%**；80mm → **29%**
- 差速车靠"左右轮纵向力差"产生横摆力矩。内侧轮卸载 → 它的 μN 下降 → 纵向力不足 → **推头、转弯半径变大、航向抖动**。所以低趴是**给差速车保抓地力**的。

**代价（有据）**：离地间隙、越障、**红外模块的最佳工作高度（1~8mm）**、装配空间。
→ **最优不是"越低越好"，而是"低到不刮底、红外模块仍在最佳高度"。**

---

## 3. "短车不稳所以要 IMU" → 因果错

差速车运动学：**ω = (v_r − v_l)/B** → 航向漂移率 dθ/ds = ε/B（ε=左右轮速失配率）。

| 失配 ε | 轮距 B | 漂移率 | 跑 5m 后偏航 |
|---|---|---|---|
| 0.5% | 117mm | 2.45°/m | 12.2° |
| 1% | 117mm | 4.90°/m | 24.5° |
| 2% | 117mm | 9.79°/m | 49° |

**轴距 L 根本不出现**。差速车走不直的真因：① 左右不一致（电机/轮径/摩擦）② 轮距 ③ 没有闭环；而且**前轮是自由随动的球脚轮 → 没有自回正力矩 → 航向误差会一直累积** ← 这才是需要 IMU/闭环的真正理由。

**IMU 的合理用途（按对我们的价值排序）**：
1. **丢线/断路时保航向**（配合里程计）← 我们丢线是常态，价值最高
2. **直角弯/环岛的偏航角积分**（龙邱用"积分角 >150 判入环、>735 预出环、>1050 判出环"）
3. **直线段角速度阻尼**（抑制画龙；多支队伍把陀螺仪 Z 轴角速度当 D 项）
→ **但它修不了错误的传感器几何或不合格的控制环**，别指望它当"短车稳定器"。

---

## 4. 车长：短是对的，但不是越短越好

**龙邱缩微电磁手册原话（最强依据）**：
> "传统车模难以适应的主要原因在于其**车身过长以及较大的转弯半径**。因此…应当着重于**减少车辆长度及减小最小转弯半径**…还需注意将**车体重心集中于转向中心附近，并尽可能降低重心高度**，同时减轻车模重量，减小惯性的影响。"

**厂商同时提醒（光电手册）**：
> "…可以缩小车模尺寸来增加容错率。然而回顾历届大赛，**大车模往往更具优势**。所以需要在**容错率和车模性能上限之间权衡取舍**。"

**为什么短有效（三个机制）**：
1. **转动惯量** I_zz≈mL²/12：车长 0.23→0.30m，转动惯量 **+70%** → 横摆响应更慢
2. **传感器前置量 = 时间滞后**：我们 213mm @1.2m/s ≈ **0.178s ≈ 36 个控制周期**（拓邱控制周期 5ms）→ 直接限制 PD 增益能开多大
3. **车头扫掠/内轮差**：直角弯内侧锥桶距线仅 12cm 的场地上，长车头最容易蹭

**顺带**：差速车在直角弯/Ω 上是**结构性优势**（舵机有死区、阿克曼限制车长、多一个轮分担摩擦），**别改成舵机**。

---

## 5. 对我们下一版的直接结论

| 项 | 做法 |
|---|---|
| 车长/前瞻 | **缩**（前瞻 213→110、总长 229→~175）✅ 已写入《下一版车型-尺寸建议.md》 |
| 低趴 | **做，但目标是"不刮底 + 红外仍在 5~8mm"**；重点是把**重物压低、靠近驱动轴**：电池贴地压轴（已做 ✓）、**PCB 别架到 4cm 高的叠层**（挪到电机后方低位） |
| IMU | **留着，暂不参与控制**；将来要用就用在：丢线保航向 / 直角与环岛偏航角积分 / 直线角速度阻尼。**不要**为"补短车稳定"而用 |
| 车轮配置 | 保持差速（别改舵机） |
| 装配细节 | IMU 那块 PCB 可考虑加**减震橡胶垫**（高频振动污染陀螺仪）；重物处理方式照头部队伍：**电池贴地/夹在两电机之间** |

---

## 6. 诚实说明（没查到的）

1. **我们的赛道规格（5m×5m、25mm 白线、R342 小圆环、Ω）没能对应到任何公开规则**（搜 "R342" 零结果）→ 校赛自定，无公开先例可对标。最接近的公开规格是第 20 届缩微组（白线宽 1.5~2.5cm、锥桶离线 ≥12cm、无路障坡道、最多 3 个断路区）。
2. **重心高度的实测数字**：全网没有智能车的重心高实测值（只有离地间隙：缩微自制 4mm、官方 B 车模 7.5/16.5mm 两档）。文中的 50mm 是估值，按它算的。
3. **"轴距 XX + 用/不用陀螺仪，因为……"的完整对照**：没找到 → §3 的结论标注为"运动学推导 + 间接证据"。
4. **配重块 / 风阻罩**：没找到任何智能车赛事用例。
5. 检索通道：CSDN 官方搜索 API + Quark/神马 + CSDN 站内定向抓取（卓晴/龙秋博客全库、参赛技术报告系列）；Bing 长尾中文查询在本环境退化严重。

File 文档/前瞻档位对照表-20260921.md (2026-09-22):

# 前瞻档位对照表 + 测试记录表（2026-09-21）

> **怎么用**：长条板每 10mm 一个孔位，从 60 到 150 共 10 档。
> **理论最优区 = 100~120mm**（下面"判断"列有依据），所以**先跑 70 / 90 / 110 / 130 / 150 这 5 档**，再在最好的那一档附近细化。
> 每跑一档，把现象填进 §3 的记录表（**我一定会问你这几张数据**）。

---

## 0. 公式与参数

- **内切量**（车头相对轨迹切进弯内的量）：`Δ ≈ d²/(2R)`
  → 车沿圆弧走时，传感器在驱动轴前方 d 处，它「切内」Δ；Δ 越大，控制器越像"提前看到弯心"，出弯车尾甩外、压到另一条线。
- **外廓外扩**（转弯时前外角扫出去的半径）：`R_out = √((R+B/2)² + L_front²)`，外扩 = R_out − R
  → 必须 **< 赛道上相邻两条线的最小间距**（这个数你要实地量！）
- **等效转向增益** ∝ d：**d 缩短多少倍，KP 起点就要放大多少倍**（表里给系数）
- **航向分辨率** = atan(12.9/d)（12.9mm = 8 路条的探头间距）：d 越短，分辨"车头歪了几度"的能力越差 → 这是"前瞻不能无限缩"的另一面

固定参数：赛道最小圆环 **R=342mm**、线宽 **25mm**、轮距按 **B=165mm**、传感支架前伸 **20mm**（板子前缘比传感器中心再前 20mm）。

---

## 1. 主表（就照这个画/跑）

| 档位 d (mm) | 内切 Δ @R342 | =几条线宽 | 内切 @R685 | **KP 起点系数**(213/d) | 航向分辨率 | 总长≈d+50 | 判断 |
|---|---|---|---|---|---|---|---|
| 60 | 5.3 | 0.21 | 2.6 | ×3.55 | 12.1° | 110 | 太近：分辨率差、易画龙 |
| **70** | **7.2** | 0.29 | 3.6 | ×3.04 | 10.4° | 120 | ✅ 测 |
| 80 | 9.4 | 0.38 | 4.7 | ×2.66 | 9.2° | 130 | 可选 |
| **90** | **11.8** | 0.47 | 5.9 | ×2.37 | 8.2° | 140 | ✅ 测 |
| 100 | 14.6 | 0.58 | 7.3 | ×2.13 | 7.4° | 150 | ★ 最优区 |
| **110** | **17.7** | 0.71 | 8.8 | ×1.94 | 6.7° | 160 | ★★ 最优区（推荐起点） |
| 120 | 21.1 | 0.84 | 10.5 | ×1.78 | 6.1° | 170 | ★ 最优区 |
| **130** | **24.7** | 0.99 | 12.3 | ×1.64 | 5.7° | 180 | ✅ 测 |
| 140 | 28.7 | 1.15 | 14.3 | ×1.52 | 5.3° | 190 | 可选 |
| **150** | **32.9** | 1.32 | 16.4 | ×1.42 | 4.9° | 200 | ✅ 测（上限） |
| ~~213（现在）~~ | ~~66.3~~ | **2.65** | 22.6 | ×1.00 | 3.5° | 263 | ❌ 现状：内切 2.6 条线宽 |

**读表要点**：
- 现状 213mm 的内切是 **66mm = 2.6 条线宽** → 换成人话：**车头常年"吃"进弯里 66mm**，这就是"过弯畸形"的几何根源。
- 110mm 时只有 **17.7mm（0.7 条线宽）**，150mm 也有 33mm（1.3 条宽）→ 都比现在好一倍以上。
- 但 60mm 也不该选：航向分辨率掉到 12°、延迟补偿不足 → 会画龙。**"短"有个下限。**

---

## 2. 外廓外扩（用 R=342、B=165 算的）

| d | 支架前伸 20 → L_front | R_out | **外扩** |
|---|---|---|---|
| 70 | 90 | 434 | +92 |
| 110 | 130 | 444 | +102 |
| 150 | 170 | 457 | +115 |
| 213（现状） | 233 | 484 | **+142** |

→ **判据**：外扩量必须 < 赛道相邻两线的最小间距（尤其**相切圆环切点**、**Ω 回头弯两条平行腿之间**）。这个数**你去场地量一下**（或量赛道图），量到告诉我，我帮你把 d 的最终上限定死。

---

## 3. 测试记录表（每跑一档填一行）

| 档位 d | FW版本 | S值(速度) | 直角弯 | 圆环 R342 | 葫芦弯 | 丢线次数/次 | 摆头? | 备注（现象原话） |
|---|---|---|---|---|---|---|---|---|
| 70 |  |  |  |  |  |  |  |  |
| 90 |  |  |  |  |  |  |  |  |
| 110 |  |  |  |  |  |  |  |  |
| 130 |  |  |  |  |  |  |  |  |
| 150 |  |  |  |  |  |  |  |  |

> 每换一档：① 把 KP 调到"不摆头"（起点 = 表里的系数 × 你在 213mm 下试出的值，或直接从 1.0 往上试）
> ② 告诉我一声 → 我这边记录串口数据（IR 位图 / 丢线 / RPM）
> ③ 最后我出"前瞻 vs 表现"对比表 + 定稿建议

---

## 4. 做长条板的注意（防返工）

1. **5mm 亚克力**（3mm 在 100mm 悬臂上会颤 → 传感器离地 5~8mm 一颤就误判，你会误判成"这档不行"）
2. **两排孔**：间距 = 8 路模块背面两条长条孔的中心距（**先量，别按感觉打**）；模块长条孔本身有 17mm 可调量 → 配 10mm 孔距，细调很够
3. **板上刻数字**（70 90 110 130 150）——不然跑完就忘了哪档
4. **M3 沉头/平头**螺钉，别凸出来刮地；每档**左右各一颗**（一颗会歪 → 左右不对称）
5. 模块**离地 5~8mm**（铜柱/垫片调），**板前端别翘**（翘 = 前瞻悄悄变大）
6. **线留 10cm 松弛**或做插座 → 换档不用重焊
7. 长条板与底板的连接处**也留 10mm 孔距**（二级调节），这样整根条能前后挪，覆盖更大范围

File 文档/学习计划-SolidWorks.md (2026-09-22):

# SolidWorks 学习路线（项目驱动 · 智能车用）

> 2026-09-16 建立。**已安装**：SW 2025，主程序 `D:\SW2025\SOLIDWORKS\SLDWORKS.exe`，桌面有快捷方式；许可服务已注册（SolidWorks Flexnet Server）。
> 目标**不是"学会 SW"**，而是**能做出智能车要用的结构件 + 会导 DXF 给激光切割 + 会装配查干涉**。

---

## 一、第一次打开先改 3 个设置

- [ ] **单位 → MMGS**（毫米-克-秒）：工具 → 选项 → 文档属性 → 单位
- [ ] **备份/临时目录改到 D 盘**：工具 → 选项 → 系统选项 → 文件位置 / 备份，默认写 C 盘（C 盘紧张）
- [ ] **只留 Toolbox 插件**：工具 → 插件，把 CAM / Plastics / Flow Simulation / Visualize 等先取消勾选（启动快）

---

## 二、只学这 4 件事（其余先跳过）

| # | 内容 | 关键点 | 用时 |
|---|---|---|---|
| 1 | **草图 + 尺寸 + 几何关系** | 选基准面 → 画直线/圆/矩形 → **标尺寸** → 几何关系（重合/平行/垂直/对称/相等）| 1 晚 |
| 2 | **特征**：拉伸凸台 / 拉伸切除 / 异型孔向导 / 圆角倒角 | 把草图变实体；孔向导打 M3 安装孔 | 1 晚 |
| 3 | **装配体 + 配合 + 干涉检查** ★ | 插入零件 → 配合（重合/同心/距离/平行）→ **干涉检查** | 1~2 晚 |
| 4 | **导出 DXF/DWG + 工程图** ★ | 零件/装配**导出 DXF** 给亚克力切割；出带尺寸工程图 | 半晚 |

**不用学**：曲面、钣金、Simulation、CAM、Visualize（渲染）。

---

## 三、用智能车当练习（4 个，越做越接近成品）

- [ ] **练习 1（热身）**：90×70×1.6mm 板 + 四角 φ3.2 孔
- [ ] **练习 2（马上能用）**：传感器支架（托板 9×3cm、高 2.3cm、带 M3 孔）→ 导出 DXF
- [ ] **练习 3（★最有价值）**：简化装配 = 底板 + 2 电机 + 2 轮 + PCB + 核心板 + TB6612 + 电池 → **干涉检查**
      要核对的尺寸：PCB 宽 **70mm** 别碰电机/轮子（电机 z=±5.0、本体内缘 ≈±3.75cm）；传感器与 PCB 净空 **0.7cm**；球脚轮转接板位置
- [ ] **练习 4（收尾）**：球脚轮**转接板** 30×30mm（两孔对底板 z=±3.0，中心对球脚轮法兰）→ 导出 DXF

---

## 四、关键尺寸速查（画图时直接抄）

| 件 | 尺寸 |
|---|---|
| 底板 | 长 **18.5cm**；宽 前 **7.5** / 中 **13.5** / 后 **15.7cm**；厚 3mm |
| 驱动轮 | 直径 **6.6cm**（半径 3.3 → 轴心离地 3.3）|
| 轴距 | **8.5cm**（前支撑 ↔ 驱动轴）；传感中心距驱动轴 **5.0cm** |
| 轮距 | **11.7cm**（后轮中心距）|
| 电机支架孔 | **17mm 正方形四角**，孔径 3.5mm（M3）|
| 8 路模块 | 长 9 × 宽 3cm，离地 1.0cm |
| 电池 | 6.4 × 3.5 × 1.8cm |
| PCB | **90×70mm**，离地 4.0cm，安装孔距 **83×62mm**（±41.5 / ±31）|
| 球脚轮 | 裸高 ≤ 33mm（总高 = 裸高 + 铜柱堆叠 = 3.30cm）|

---

## 五、怎么学（本项目约定）

1. 卡住 → 截图发我，我针对性讲
2. 看完一节 → **用自己的话讲一遍**，我批改（沿用"自述理解 → 批改"的方式）
3. 练完的模型 → 截图发我，我对着上面的尺寸链核（孔位/净空/干涉）
4. 学的过程中记 CSDN 素材（"用 SW 给智能车建模"这个选题很实用）

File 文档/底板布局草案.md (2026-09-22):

# 底板布局草案（新车 · v1）

> 2026-09-11 出稿。配套 `新车设计书.md` §4 机械结构。
> **状态**：几何/尺寸链已校核（可下料）；**标 ⏳ 的尺寸需实物到货后复核**。
> 坐标约定：**驱动轴为原点 x=0**，向**车头为正**；宽度方向为 z（左负右正）。

---

## 一、两个已定项（本次结论）

### 1.1 前支撑类型 → **球脚轮（2026-09-16 改定）**，配「M3 铜柱 + 垫片」可调高度

> ★ **2026-09-16 变更**：前支撑由"麦轮 0°"改为 **球脚轮（万向滚珠 / 牛眼轮）**——滚动摩擦最小、原地转最省力，
> 本来就是原文档的"**推荐备选**"。下面麦轮 0° 的论证保留作历史记录。
>
> **球脚轮选型算法（务必遵守）**：
> ```
> 总高 3.30cm = 球脚轮裸高 + 铜柱/垫片堆叠     堆叠只能加、不能减
> → 球脚轮裸高必须 ≤ 33mm，且尽量接近 33mm（否则要垫很长的堆叠）
> → 推荐：球径 20~25mm 法兰式万向球（总高约 26~31mm），配 2~8mm 铜柱/垫片凑 3.30cm
> → 禁止：球径 ≥30mm（总高 >34mm，矮不下来）；螺杆式/弹簧式（无法与铜柱对接）
> ```
> **装配注意**：球脚轮法兰孔距一般 20~30mm，与底板"前支撑孔 z=±3.0cm"对不上
> → 用一块 **30×30mm 小转接板**（亚克力边角料/废 PCB）：两孔对上底板 z=±3.0，球脚轮拧在转接板下，中间夹铜柱堆叠调高度。

**结论**：用**麦轮**，但**不许按 45° 装**——要装成 **0°（滚子轴线与前进方向垂直）**。

**为什么 45° 不行**（这是"麦轮能不能用"的真正分水岭）：

| 工况 | 麦轮装角 | 滚子自由滚动方向 vs 实际速度方向 | 结果 |
|---|---|---|---|
| 沿车头方向前进 | 0° | 同向 | 滚子纯滚动，**零阻力** |
| 沿车头方向前进 | 45° | 差 45° | 需 71% 侧向滑移 + 29% 滚动 |
| **原地转 / 过急弯** | 0° | 滚子纯滚动 | **零阻力** |
| **原地转 / 过急弯** | 45° | 差 45° | **侧向刮擦 → 阻力** |

- 定量：前轮负载 ~200g 时，45° 装的侧向刮擦阻力 ≈ **1.1 N**；0° 装 = **0 N**。
- **更致命的是它不恒定**：麦轮一圈内装角在 0°↔45° 之间周期变化（1 圈 = 8 或 9 个滚子），
  → 阻力随车轮转角**脉动**，且**前进/后退/左转/右转四个方向阻力各不相同**。
  → 转弯时前轮"时抓时滑"，表现就是**急弯忽左忽右、原地转卡顿**——正好踩中"复杂赛道"的坑。
- 又因为它是**被动轮（不驱动）**，四麦轮那种"前后左右侧向力两两抵消"的前提根本不存在，
  麦轮唯一的优势（全方位平移）用不上，缺点（滚子刮擦、脉动、贵、重、缝里卡灰）全留着。

**为什么 0° 装就成立**：
0° 时滚子轴线垂直于车头方向 → 沿车头滚动时滚子**纯滚动**；车身绕前支撑竖直轴扭转时也一样，
因为滚子磨损后天然形成"圆柱面"绕着竖直轴转——**效果等同于一个不带叉子的万向轮**。
（这也是"麦轮平装/全向轮"的用法，常见于无动力随动轮。）

**"那买个万向轮不更省事？"——是的**，所以给你留了备选（见 §1.2），
**0° 麦轮是"既想用麦轮、又不想卡"的折中**，两者都满足硬指标。

**★ 硬指标（不论选哪个都必须满足）**：
```
前支撑【触地面 → 顶面(与底板贴合面)】= 3.30 cm = 驱动轮半径
```

**高度可调机构（★防"买错就返工"的关键设计）**：
```
底板底面 ────────┬──────── M3 螺钉
                 │  ← 垫片（0.5 / 1.0 / 2.0mm）微调
              铜柱 │  ← M3 铜柱/垫片堆叠（长度 = 3.30 − 裸高）
                 │
        麦轮/万向轮顶面 ── 支撑触地面 y=0
```
| 支撑裸高（安装面→触地面） | 堆叠 = 3.30 − 裸高 | 凑法 |
|---|---|---|
| 3.30cm | 0 | 轮毂/支架直接贴底板（垫片微调） |
| 3.00cm（★60mm 麦轮，推荐买这个） | 3mm | 3mm 或 2+1 垫片 |
| 2.80cm | 5mm | 3+2 垫片 |
| 2.30cm | 10mm | 3+3+3+1 垫片 |

> ⚠️ **2026-09-11 修正**：旧表把"堆叠长度"误写成"= 裸高"（照旧表 60mm 麦轮要配 30mm 铜柱 → 总高 6.0cm，车头翘 2.7cm）。
> 正确规则：**总高 3.30 = 裸高 + 堆叠 → 堆叠 = 3.30 − 裸高**。
> **采购清单不变**：垫片足够凑 0~13mm 任意堆叠；20/25/30/33mm 铜柱留给 PCB 抬高等其他用途。
> ★**装配细节**：裸麦轮当 0° 随动轮必须能绕轴自由转 → M3 螺钉穿轮毂作轴 + 尼龙锁紧螺母留 ~0.5mm 轴向旷量（或买带支架款），装车当天验证。

> **好处**：买回来的支撑高度**不用"刚好"**，靠铜柱+垫片凑到 3.30cm，
> 彻底避开上次"万向轮高度不匹配 → 白装一下午"的坑。
> **铜柱下料清单（下单时一次买齐）**：M3 铜柱 20/25/30/33mm 各 4 根 + **M3×5mm ×4（PCB 抬高用）**，M3 垫片 0.5/1/2/3mm 各 20 片；**前支撑推荐买 60mm 麦轮 ×2**（1备1）。

### 1.2 备选方案（如果不想要麦轮）

| 方案 | 优点 | 缺点 | 结论 |
|---|---|---|---|
| **球脚轮（万向滚珠）** | 滚动摩擦最小、原地转最省力、最矮、便宜 | 需选到接近 33mm 总高的型号，否则垫片要堆高 | **推荐备选**，追求急弯性能选它 |
| **双轮万向脚轮** | 最稳、承重最大（>5kg），行李箱脚轮满街都是 | 略重，摆动有回正力矩 | 稳妥派 |
| **滑撬（POM 圆头螺栓/尼龙滑块）** | 最轻、最矮、**不可能卡死**、高度无级可调 | **滑动摩擦大**，原地转比滚动费力 | 赛道是光滑白板时可选 |
| **麦轮 45°（学长那种）** | 手感"专业" | 见 §1.1，急弯会脉动卡顿 | ❌ 不推荐 |

### 1.3 电池高度 → **1.8 cm**（待实测确认）

- 已知 长 **6.4** × 宽 **3.5** cm；高度按 **1.8cm** 建层高（2S 2200mAh 常见厚度）。
- ⏳ **到货/现有电池请用卡尺量最厚处（含平衡头、线受压处），量最大处**，量到就替换本数字。
- 影响：电池决定"底层高度 0.3~2.1cm"和整车高度。**若实测 >2.0cm，只需把 PCB 铜柱加高即可，布局不用重画**（见 §3 可调余量）。

### 1.4 降压模块 → **v1 外置小模块**（2026-09-11 定）

- 决定：**DCDC 暂不集成**，v1 用**外置成品降压模块**（MINI360 ≈2.2×1.8cm 或 MP1584 模块 ≈3.6×2.2cm，≥2A，¥3~5）出 5V；3.3V 由板上 AMS1117-3.3 从 5V 降。
- ★**旧大模块（4.4×6.7cm）放不下**：按 §2.1 布局逐位置核实——顶部后区被电机（z=±5.0, x=−6.0~+1.0）占、中部被 PCB 占、前区板宽仅 7.5 且挂传感器、电池旁纵向 6.4+6.7=13.1 > 可用 10.5，**全冲突** → 退役留旧车。
- v2 再板上集成（备选存档：MP1584EN 首选 / TPS5430）。
- 小模块安装位见 §2.1 表；**上电前先用万用表把输出调准 5.0V 再插板**。

---

> ⚠️⚠️ **2026-09-18 重大变更：本车实为"等比复刻学长的车"** ⚠️⚠️
> 用户确认：结构**几乎 1:1 复刻学长的车**（除了前轮/前支撑不同），**不是**按本文档的 185/157/轴距 8.5/传感距 5.0 那套尺寸做的。
> **已实测：传感中心 距 驱动轴 = 213mm**（本文档原定 **50mm** → 作废，以学长车为准）。
> 因此本文件中所有"我们自算"的结构尺寸（板长 185、宽度 75/135/157、轴距 8.5、传感距 5.0 等）**仅供参考/作废**，实际以学长车实测为准。
> **⏳ 待补实测**：板长、板宽（前/中/后）、前后轴距、轮距、驱动轮直径、传感器模块尺寸、前支撑到驱动轴距离。
> **★ 不受复刻影响的硬约束（必须按我们的来）**：
> ① **前支撑总高 = 驱动轮半径**（球脚轮 + 铜柱垫片凑 3.30cm，若轮径不同则随之改）
> ② **PCB 的 4 个安装孔**必须与已下单的 PCB 一致：**孔距 X 向 62 × Y 向 83**（即 ±31 / ±41.5），且 PCB 周围要留出 90×70、离地 4.0cm 的安装空间
> ③ 所有接口位置要能对上 PCB（电机 6P×2、8路 10P、J_POWER 等）
> ④ 电池/PCB 用长条孔留 ±2cm 调重心余量
> **★ 调参影响**：传感前悬从 5cm 变 21.3cm → 几何增益约 **4.3 倍**，KP 需按比例调小（旧车 KP=10 → 起步试 **2~3**），速度自适应阈值也要重调。

---

> **★ 用户实际布局（2026-09-18 提供，单层紧凑板，无空余）**：
> 从**驱动轴（后轮）**往车头排：**降压模块段 38mm**（模块横放，占纵向）→ **PCB 段 70mm** → **车头球脚轮段 74mm**；
> **传感中心距驱动轴 = 213mm**，**板总长 ≈ 229mm**。
> → 本文档原来的"传感距驱动轴 50mm"是**理想目标值，单层板不可能达到**，**正式作废**，以 213mm 为准。
> **代价与对策**：前悬大 = 有提前量（可预判弯道），但等效几何增益约为 50mm 方案的 4.3 倍 → **KP 起步调小（旧车 10 → 试 2~3）**，速度自适应阈值重调，必要时加 D 项/低通滤波抑制摆头。

---

> **★ 前瞻距离（= 传感中心到驱动轴）行业数据 · 2026-09-18 查证（来源：CSDN）**：
> - **定义**（CSDN《智能巡线小车的设计》）："**前瞻 D1 是指红外巡线电路板到动力车轮的距离**。合适的前瞻值可以提前获取黑线信息，减少反应延迟，提高循迹效果。"
> - **竞赛级 CCD 车实测**（CSDN 经验贴，19 届 STC-CCD）："**下排 CCD 前瞻 35~45cm、上排 60~75cm 效果最好**；把上排调到 **80cm，圆环识别率直接掉到 50% 以下**"（→ 前瞻过长会失稳）
> - **视觉方案**（CSDN《…从图像处理到PID调参》）：图像底对应车头前 **15cm**、顶部对应 **120cm** 是理想范围；**判据：前瞻 ≥ 车速 × 链路总延迟**（1m/s × 80ms ≈ 8cm）
> - **电磁单车竞赛**：前瞻固定于车前方 **20cm**、高 15cm
>
> **对照本车 213mm**：车速上限 ≈1.3m/s（7.4V/380rpm/φ66 轮）→ 延迟位移 ≈10cm → **前瞻余量近 2 倍 ✓ 合理**；
> 比玩具级红外循迹（5~15cm）大（提前量更足），比竞赛级 CCD 车（35~75cm）小（更保守好调）。
> → **结论：213mm 保留不改**；原文档的"5.0cm"作废（那是套用"传感在两轮之间"车型的经验，与本车布局无关）。
> → 调参含义：前瞻大 → 等效增益高 → **KP 起步试 2~3**（旧车 10），并配合 D 项/低通滤波压摆头。

---

## 二·0、★底板外形定义（2026-09-16 补：原来只给了三个宽度，这里定出轮廓）

**坐标系**（画图必须按这个，否则孔位全错）：
- **x 以驱动轴为 0**，**+x 向车头**、−x 向板尾；**z 为宽度方向**（左 −、右 +）；板厚 **3mm**
- 总长 **185mm**：板头 **x=+100**，板尾 **x=−85**
> 📌 **SolidWorks 建模时坐标换法**（2026-09-16）：SW 里用 **Y = 车长方向**、**X = 宽度方向**、**X=0 为对称轴**（先画右半边再镜像）。
> 对应关系：**文档 x ↔ SW 的 Y**、**文档 z ↔ SW 的 X**，数值一一照抄。**+Y 朝车头**（板头 Y=+100）。
> ⚠️ 板形**不对称**（前端 75 vs 后端 157），镜像后务必量：Y=+100 处宽 75、Y=−85 处宽 157。

**轮廓（窄头宽尾，四段 + 两段过渡）**：

| x 范围 | 半宽 \|z\| | 全宽 | 说明 |
|---|---|---|---|
| +100 ~ +30 | ±37.5 | **75** | 前段（长 70）：前支撑 x=+50、传感器支架都在这里 |
| +30 ~ +15 | 线性过渡 | 75 → **135** | 斜边过渡 |
| +15 ~ −10 | ±67.5 | **135** | 中段（长 25）：**含驱动轴**，驱动轮在此处略微探出板外 |
| −10 ~ −30 | 线性过渡 | 135 → **157** | 斜边过渡 |
| −30 ~ −85 | ±78.5 | **157** | 后段（长 55）：电机支架孔、降压模块、电池槽 |

- 所有外角**倒圆 R5**（防割手、也避免亚克力尖角开裂）
- 若激光切割厂家要求单文件，直接导出 DXF（见 §四 末尾）

---

## 二、底板俯视布局草案

### 2.1 纵向定位表（★核心，以驱动轴 x=0 为基准）

| 部件 | 纵向中心 x (cm) | 纵向占用 (cm) | 横向占用 (cm) | 高度区间 (离地, cm) | 备注 |
|---|---|---|---|---|---|
| **前支撑（麦轮0°）** | **+5.0** | 3.85 ~ 6.15 | 两脚 z=±**3.0** | 0 ~ 3.3 | 孔距 23mm，**装在传感器两侧** |
| **8路红外模块** | **+5.0** | 0.5 ~ 9.5 | \|z\| ≤ 1.5（宽3） | **1.0 ~ 2.5** | 传感器底面离地 **1.0cm**、**0°平行** |
| 传感器支架 | +5.0 | 0.5 ~ 9.5 | 同模块 | 2.5 ~ 3.3 | 高 **2.3cm**，自制 |
| **驱动轴 / 驱动轮** | **0**（基准） | ±3.3（轮） | z=±5.85 | 0 ~ 6.6 | **轮半径 3.3**，轴心离地 3.3 |
| 电机 + 支架 ×2 | −2.5 | −6.0 ~ +1.0 | z=±5.0 | 2.5 ~ 6.0 | 支架孔 17mm 四角，M3 |
| **电池 2S 2200** | **−1.2** | −4.4 ~ +2.0 | \|z\| ≤ 1.75 | 0.3 ~ 2.1 | **压驱动轴、贴最底层** |
| **PCB 9×7 (90×70)** | **0.0** | −4.5 ~ +4.5 | \|z\| ≤ 3.5 | 4.0 ~ 5.6 | 铜柱抬到离地 4.0；4 个安装孔见 §四（孔距 83×62） |
| **降压小模块 (v1)** | **−6.8** | −7.9 ~ −5.7 | \|z\| ≤ 1.8 | 3.6 ~ 5.6 | 板顶后部中央（见 §1.4；大模块放不下→换小模块） |

> ⚠️ **PCB 与传感器纵向重叠（0.5~5.0cm）是允许的**：传感器只占中间 3cm 宽（\|z\|≤1.5），
> PCB 抬高到离地 4.0cm，而传感器顶面 2.5cm、支架顶 3.3cm → **垂直方向留 0.7cm 净空**，互不干涉。
> ⚠️ **PCB 宽度硬约束：横向 ≤ 7cm（z ±3.5）**（2026-09-11 补）：电机本体在 z=±5.0、直径约 25mm（内缘 ≈±3.75cm），
> 车轮内缘 ≈±4.55cm；而 PCB 高度带 4.0~5.6cm 与电机带 2.5~6.0cm、车轮带 0~6.6cm **重叠** → **板子可以加长，不要加宽**。
> ⚠️ **PCB 与底板的 4 个安装孔必须同坐标**（建议 **x=±3.5cm、z=±3.0cm**；**\|z\| ≤ 3.0 是硬约束**，超过会撞电机）。

### 2.2 俯视图（示意，非比例）

```
        板头 x=10.0                     驱动轴 x=0                   板尾 x=-8.5
   ┌───────────────────────────────────────────────────────────────────────────┐
   │                       ┌───────────────────────────────┐                   │
   │   ┌──┐                │                               │                   │
   │   │麦│ ← 支撑(两脚)    │      P C B   7 × 10cm         │                   │
   │   │轮│   z=±3.0cm     │   (抬高到离地 4.0cm)          │                   │
   │   └──┘                └───────────────────────────────┘                   │
   │        ╔═══════════════════════════════════════╗                            │
   │        ║   8路红外模块  9cm × 3cm  离地1.0cm  ║  ← 与支撑纵向重叠但错开横向  │
   │        ╚═══════════════════════════════════════╝                            │
   │                            ┌────────────┐                                   │
   │                            │ 降压小模块 │ ← 板顶后部中央 x≈−6.8 (v1 外置)  │
   │                            └────────────┘                                   │
   │                                  ┌───────────────┐                          │
   │        ════════╤══════════════   │  电池 6.4×3.5 │   ════════╤══════════    │
   │        左轮 ◯  │                 └───────────────┘   右轮 ◯ │                │
   │      (z=-5.85) │←──── 轮距 11.7cm ────→│        (z=+5.85)  │                │
   └────────────────┴────────────────────────────────────────┴───────────────────┘
                    板宽: 前 7.5 / 中 13.5 / 后 15.7cm
```

### 2.3 侧视图（★防翘头校核）

```
  离地
  5.6 ┌──────────────────────────────┐  ← PCB 顶
  4.0 └──────────────────────────────┘  ← PCB 底（铜柱抬升段）
  3.3 ═══════════════════════════════════════  ← 底板底面 ★全车基准高度
  2.5      ┌──────────────────────┐            ← 传感器顶 / 支架顶 3.3
  2.1      ▓▓▓▓▓▓ 电池 ▓▓▓▓▓▓                   ← 电池顶（贴底板上表面）
  1.0      └──────────────────────┘            ← 传感器底面 ★离地 1.0cm，0° 平行
  0.3    ▓▓▓▓▓▓▓▓▓▓▓▓▓▓▓▓▓▓                    ← 电池底
  ──────────────────────────────────────────── 地面 y = 0
         ↑                      ↑
     前支撑触地            驱动轮触地
     (总高 3.3cm)         (半径 3.3cm)
```

**★ 防翘头等式（唯一硬约束）**：
```
前支撑触地面→顶面  3.30 cm   ==   驱动轮半径  3.30 cm
```
只要这一条成立，三点着地、底板水平、不翘头。

---

## 三、重心与载荷分配（可调余量）

### 3.1 质量估算与重心

| 部件 | 质量 (g) | x (cm) | 力矩 (g·cm) |
|---|---|---|---|
| 8路传感器 + 支架 | 100 | +4.5 | +450 |
| 前支撑总成 | 70 | +5.0 | +350 |
| 驱动轮 + 轮毂 ×2 | 90 | 0 | 0 |
| 电机 + 支架 ×2 | 320 | −2.5 | −800 |
| 电池 | 115 | −1.2 | −138 |
| PCB + 元件 | 120 | 0 | 0 |
| 底板 + 紧固件 + 线材 | 250 | −2.0 | −500 |
| 降压小模块 (v1) | 10 | −6.8 | −68 |
| **合计** | **≈ 1075** | **x_cg ≈ −0.7** | −706 |

> ⏳ 质量为**估算**（按同类件经验值），到货后称重替换即可，方法不变。
> ⚠️ **2026-09-11 重算修正**：原表合计力矩 −638 g·cm ÷ 1065 g 应为 **x_cg = −0.60cm**（原文写 +0.1 系加错）。
> 计入小模块后为 **−0.7cm**。结论不变：**重心仍基本压驱动轴（轴后 0.7cm），后驱布局成立**。

### 3.2 三点载荷（轴距 8.5cm）

```
F_front = W × |x_cg| / 轴距          （以驱动轴取矩）
```

| 项 | 数值 |
|---|---|
| 总质量 | ≈ 1075 g |
| 重心 x_cg | **≈ −0.7 cm**（轴后 0.7cm，仍基本压驱动轴）★2026-09-11 重算修正 |
| 轴距（支撑↔驱动轴） | **8.5 cm** |
| **前支撑静载** | ≈ 83 g（**7.7%**）→ 轻载（原表 12g/1.1% 系重心加错连带，已修正） |
| **单侧驱动轮静载** | ≈ 496 g（**46.1%**）×2 → 抓地力充裕 |

**解读**：重心压在驱动轴上，是**牵引力最优**的布局（后驱最怕重心靠前，起步/加速打滑）。
代价是**前支撑几乎不受力 → 只起"防点头"作用，不做承载**，所以：
- ✅ 前支撑**规格要求很低**（承 1kg 足够，随便买个小的都行）
- ✅ 原地转时前轮几乎无摩擦阻力 → **差速原地转更利索**
- ⚠️ 但**前支撑"必须接触地面"**——若高度差 1mm 悬空，车头就会点头/抖动，
  所以 §1.1 的**可调高度机构是必须的**，不是可选项。

### 3.3 ★可调余量（现在不用改，出问题再调）

| 现象 | 调整手段 | 效果 |
|---|---|---|
| 前支撑太轻、过坎抖 | 电池**前移** ≤2cm | 前载 1% → 6%，更贴地 |
| 起步/加速打滑 | 电池**后移** ≤2cm | 驱动轮更压，牵引力更大 |
| 高度差一点 | 加/减垫片 | 直接凑 3.30cm |
| 板面干涉 | 抬 PCB 铜柱 | 每 +1cm 加 1cm 净空 |

> **★ 布局的鲁棒性设计**：电池和 PCB 都用**长条孔/多孔位**固定，
> 允许 ±2cm 纵向滑动调重心——**装好后仍可调**，不用重画底板。

---

## 四、加工孔位清单（下料用）

| # | 孔位 | 数量 | 孔径 | 位置（x 距驱动轴） | z |
|---|---|---|---|---|---|
| 1 | 电机支架固定 | 8 | **φ3.5**（M3） | x=−2.5（17mm 四角） | ±5.0 ±0.85 |
| 2 | 前支撑安装 | 2 | **φ3.2**（M3） | x=+5.0 | **±3.0** |
| 3 | 传感器支架 | 2~4 | φ3.2 | x=+5.0 | ±2.0 |
| 4 | PCB 铜柱 | 4 | φ3.2 | **x=±41.5**（纵向孔距 **83.000**） | **±31.0**（横向孔距 **62.000**） |
| 5 | 电池扎带槽 | 2 | 宽 5 长条 | x=−1.2 | ±2.2 |
| 6 | 降压小模块固定 | 2 | **φ3.2**（M3）或扎带槽 | x=−6.8 | ±1.5（按实物孔距微调） |

**加工方式建议**：亚克力 3mm 激光切割（快、便宜、好改）→ 验证 OK 再考虑 3D 打印/PCB 兼作。
**★ 别一上来就用 PCB 兼作底板**：PCB 打完样就固定了，改孔 = 重新打样花钱；
先用亚克力验证几何，确认后再决定是否让 PCB 兼作。

---

## 五、⏳ 待复核项（到货后填）

- [ ] **前支撑裸高**（触地面→顶面）实测 → 定铜柱长度
- [ ] **电池实际高度**（最厚处）→ 若 >2.0cm，PCB 铜柱加高
- [ ] 电机支架实物孔位是否 17mm 四角、孔径 3.5mm
- [ ] 8路模块背面 1.7cm 长条孔的实际孔距 → 定支架孔位
- [ ] 整车称重 → 替换 §3.1 估算质量
- [ ] 三点着地实测：塞尺检查前支撑是否悬空（目标：垫不进 0.5mm）

---

*（本草案随讨论更新；定稿后并入 `新车设计书.md` §4）*

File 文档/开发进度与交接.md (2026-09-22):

# 开发进度与交接

> ⚠️ **历史文档（内容截至 2026-09-08，2026-09-18 标注）** —— **别再当现状读**。
> 最新状态请看：**`对话记忆与交接-20260910.md`**（交接总入口）+ **`底板布局草案.md`**（结构尺寸权威）+ **`新车设计书.md`**（电气/BOM）。
> 本文件保留价值：旧车(test16)的完整开发史、踩过的坑、CSDN 养号计划、代码学习进度。其中"下一辆车方案"等段落已被后续决策**取代**。

> 写于 2026-08-16，更新至 2026-08-20。给"以后的我"和 Claude 看的进度快照，新对话开始时先读这份 + `循迹小车使用手册.md`。

> ⭐ **2026-09-10 重要约定（Claude 必守）**：用户最大的问题是"**动手前没想清楚细节，导致反复返工**"。**以后每次动手（下单/买件 / 画 PCB / 画底板 / 搭车 / 写代码）之前，Claude 必须主动按 `动手前考虑清单.md` 帮用户把关**（尺寸、配套耗材、装起来什么样、最大风险、兜底），不用用户提。血泪案例：搭车翘头(没买匹配万向轮)、电机到了却没线。

## 已完成

### 基础功能（8/16 前）
- [x] 双电机驱动：TIM2 CH3/CH4 PWM（10kHz）+ DIR1~4 方向控制，`change1/change2()` 支持正反转/停止
- [x] 修复历史 bug：CH4 PWM 未启动、change2 误写 GPIOA、负速度取绝对值、删废弃宏
- [x] 5 路循迹 + 2 路霍尔 + USART1 串口调试全部配置完毕
- [x] 循迹 P 控制代码：`read_sensors()` 加权误差 + `line_follow()` 差速 + 丢线保护
- [x] 工程已复制到本文件夹（桌面 `Desktop\test16`），以后改这里

### 8/19 联调（面包板整车跑通）
- [x] **串口在线调参**：`P <KP>` / `S <速度>` / `T <1|2> <速度>`（单电机测试）/ `H`（读PA11/PA12电平），不用重烧
- [x] **修复串口 RX 收不到**：`usart.c` 里 PA10(RX) 原被配成 AF_PP 推挽输出顶住输入信号；改为 `GPIO_MODE_INPUT`+NOPULL（对照 test151 工程确认）。⚠️ **CubeMX 重新生成会冲掉此修复**，需手动把 PA10 改回输入模式
- [x] **修复电机2 方向反**：TB6612 B通道实测反转，`change2()` 里 DIR3/DIR4 电平对调（没动线）
- [x] **修复霍尔 RPM 恒 0**：`HAL_GPIO_EXTI_Callback` 用 `==` 判断合并掩码(0x1800)永远不相等 → 改**按位与 `&`**；随后 `EXTI15_10_IRQHandler` 改**拆成单脚调用** `HAL_GPIO_EXTI_IRQHandler(GPIO_PIN_11)` + `(GPIO_PIN_12)`（否则任意一路触发两路一起计数，RPM1恒等于RPM2）
- [x] **LINE_ACTIVE_LEVEL 改 `GPIO_PIN_SET`**：本模块是"白板触发"型（黑线灯灭/DO高、白板灯亮/DO低），黑线输出高才算检测到
- [x] 调参助手脚本 `tune.ps1`：Read(监视)/Send(发命令)/Log(记录CSV)/Tune(摆头分析)/Sym(双电机对称性)
- [x] 底板资料：`画板手册.md`（含 §7 底板设计 + §7.5 BOM）+ `接线对照表.html`；**底板已下单**（PCB 73.8×121.8mm，等收货）

### 8/20 下地循迹成功（重要里程碑）
- [x] **转向逻辑修复**：实测确认映射 **电机1(A通道/change1/PA2/PWMA)=左轮、电机2(B通道/change2/PA3/PWMB)=右轮**；`line_follow()` 原来 `m1=base-corr / m2=base+corr` 转向反了（疯狂左转），已改为 **`m1=base+corr`(左) / `m2=base-corr`(右)**——线偏右→左轮加速右轮减速→右转追线
- [x] **左轮电机线虚焊**（8/20）：TB6612 B通道电机输出线虚焊导致左轮时转时不转/疯狂左转，电工胶带固定后正常
- [x] **下地循迹成功**：S=40 + KP=10 下**连续循环跑圈、极限 360° 大掉头完美处理**（跑到串口线打结才停 🤣）；S=50 大掉头会脱线

## 当前状态（2026-08-20 晚）

- **循迹功能已闭环**：传感器→P控制→差速→电机全通，面包板丐版能稳定跑圈
- **已验证参数（到货后照抄）**：`KP=10`、`S=40`（起步稳妥档）、`LINE_ACTIVE_LEVEL=GPIO_PIN_SET`、转向映射（电机1=左、电机2=右）
- **串口命令集**：`P <KP>` / `S <速度>` / `T <1|2> <速度>`（T 0 0 停）/ `H`；掉电恢复默认（SP=60、KP=10）
- **霍尔**：左右独立计数正常（PA11=左/电机1，PA12=右/电机2）；左600/右480 的对称差待查（见待办）
- **电源方案**：电源稳定模块给全车供电（核心板+传感器+VM），ST-Link 仅烧录；**共地必须保持**
- **已知现象**：车悬空时传感器全读 1（IR:11111 正常，无反射=像黑线）；放浅色桌面全读 0
- **测试习惯**：每次测试前 Claude 先发消息预告；车离地+LED全灭才安全；串口测试前需开电源模块

## 待办（按顺序）

1. **底板到货后迁移**：焊接（按 `画板手册.md` §7.5 BOM）→ 模块从面包板搬到底板 → **照抄已验证参数**（KP=10、SP=40、转向映射、LINE_ACTIVE_LEVEL）→ 按老流程验证（串口→方向→IR→RPM→下地）
2. **霍尔对称差 20%（左600/右480）**：右轮霍尔挪近磁铁（<5mm）→ 对调模块判断灵敏度 vs 真慢 → 真差就加右轮速度补偿（此问题在下地时影响不大，P控制能修正，可延后）
3. **完全体精调（比赛目标：十字 + 锐角弯，按优先级）**：
   ① **速度自适应**：直道加速、弯道减速（用 IR 误差判断弯道→自动调 SP；重车+锐角弯的必做项）
   ② **控制周期 20ms→10ms**：高速时修正密度翻倍
   ③ **十字检测**：5 路全触发时判为十字→直行不转向（十字最容易乱修）
   ④ **锐角丢线处理**：丢线先保持原方向一小段，仍找不到再原地转圈找线
   ⑤ **模拟量 ADC**：模块有 AO 输出→改读连续误差（误差从 5 档变连续，精度天花板最高）
   ⑥ 直道摆头就降 KP、弯道冲线就升 KP；需要时加 D 项
4. 以后想升级：`line_follow()` 里加 D 项抑制摆头、I 项消除恒偏差

## 已知坑（比赛前必查）

- **电池电压不足 = "电机响但轮子不动"**（2026-08-20 实测确认）：锂电池低电时电机嗡嗡响但转不动，极易误判成代码/死区问题。**比赛/调试前先确认电池满电**（或万用表量 VM 电压）
- **速度参考**：轮径 66mm，SP=40 空载约 1.9 m/s（左600/右480 RPM 平均），落地约 1.3~1.6 m/s ≈ 5 km/h
- **车悬空时 IR:11111 正常**（无反射=像黑线）；放浅色桌面全 0
- **测试习惯**：每次测试前 Claude 先发消息预告；车离地+LED 全灭才安全；上电后先确认 SP 再起步

## CSDN 养号进度（2026-08-25 启动）

- **目标**：记录学习过程、建立技术影响力、为求职/考研复试积累作品
- **平台**：主发 CSDN（可一键分全平台）
- **内容矩阵**（16 主题×3 平台排期表已规划，见 ChatGPT 记录）
- **已写**：
  - [x] 文章1《串口接收原理》：逐字节攒命令 + 寄存器操作（RXNE/ORE/清标志），**边学边记录，真学习**
  - [ ] 【已存草稿】B6 PID 调参实战（`CSDN-B6-PID调参实战.md`，从疯狂左转到完美跑圈，50 坑清单已整理）
  - [ ] B2 画板全流程、B5 红外原理、C1 项目复盘（待写）
- **风格建议**：标题带痛点关键词、开头先讲"解决什么问题"、补完整代码 + 配图占位、结尾埋系列钩子
- **发布**：每篇配图（豆包生成封面提示词已给）、工作日晚 20-21 点发
- **王牌**：B6 PID（真实数据 KP=8/KD=30/蛇形→PD修复/丢线旋转）

## 代码学习进度（边学边养号）

- [x] **已学（串口 + 循迹核心）**：
  - `main()` 主循环非阻塞结构、`test_mode` 单电机测试
  - HAL_NVIC_EnableIRQ（NVIC 总开关）、`USART1->CR1 |= USART_CR1_RXNEIE`（寄存器置位）
  - ORE 溢出原理、HAL 状态机（RxState）、HAL 版死锁 bug vs 寄存器版自愈
  - 回调函数 vs 中断函数区别
  - **串口逐字节攒命令**：cmd_line/cmd_len/cmd_ready（中断攒 + 主循环取，volatile 作用）
  - **寄存器操作**：`USART1->DR & 0xFF`（取字节）、SR 一次快照多次判断、`sr & USART_SR_RXNE/ORE`（状态灯）、读SR再读DR清ORE（自愈）、溢出丢字节但不补发
  - **串口命令解析 process_command**：首字母转大写 `&0xDF`、atof 跳过首字母+空格、`+0.5f` 四舍五入、**非阻塞 if(!cmd_ready)return**、命令协议分派
  - **循迹 read_sensors**：5 路加权 `{-2,-1,0,1,2}`、中间=0、丢线处理（last_error 假丢线 / line_lost 真丢线旋转 / 超时停车）
  - **循迹 line_follow（PD 差速）**：`corr = P项 + D项`、`d_term = e - last_e`、m1=base+corr / m2=base-corr 差速转向、限幅±99
  - **重点纠偏**：☆ 判断"线在左/右"看 `e` 符号；判断"误差恶化/回正"看 `d_term` 与 `e` 是否同号；☆ P带方向、D带趋势、异号即刹车；☆ corr=P+D 代数和，符号相反时 D 在抵消 P
- [ ] **待学**：
  - `speed_report()` RPM 换算、EXTI 霍尔计数
  - `tim.c/usart.c/gpio.c` 外设初始化（扫一眼即可）
  - 循迹迷宫收尾：为什么 KP=8 甜点（调参数据已录 CSDN）
- **学习方法**：先 P 后 D（先懂控制器再懂底层），边学边写文，不懂就问坚持【一个点一问】，学会用"反例验证逻辑"（拿自己调车现象对代码）
- **Obsidian 知识库已建**（`C:\Users\asus\Desktop\石头\Obsidian知识库`）：
  - [x] `嵌入式\STM32\USART 串口.md`（串口接收+命令解析完整笔记）
  - [x] `控制原理\PD 差速：D项同异号决策表.md`（同号/异号 + mermaid 图解 + 算例）
  - 主索引 `[[USART 串口]]` 双链已点亮
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

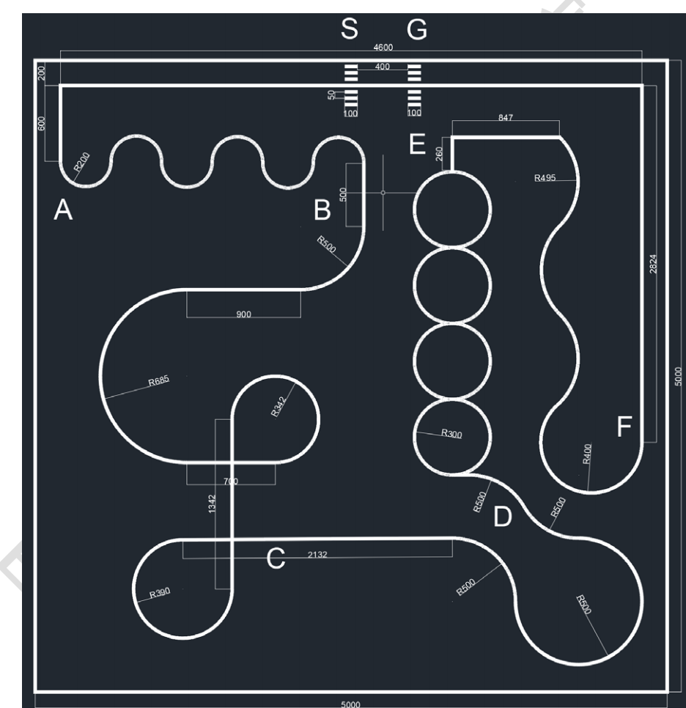
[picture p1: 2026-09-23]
微信图片_20260922161810_245_21.png

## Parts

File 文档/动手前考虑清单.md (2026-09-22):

# 动手前考虑清单（防踩坑）

> **用途**：每次"下单/买件 / 画 PCB / 画底板 / 搭车 / 写代码"**之前**先过一遍，避免"没想清楚就动手 → 返工浪费"。
> **约定**：以后每次要动手前，**Claude 主动按本清单帮我把关**（用户不用记）。
> 血泪教训：2026-09-10 搭车翘头（没买匹配的万向轮）、电机到了却没线（没算配套耗材），白白浪费一下午。

---

## 一、通用模板（任何事前，先自问）
1. **目的**：做这个是为了什么？做成"什么样"算成功？
2. **要哪些件**：不光是主体，还有**配套耗材**（螺丝/铜柱/线材/连接器/胶带/电源）——★最容易漏。
3. **关键尺寸/接口**：实际装起来会是什么样？会不会互相打架？
4. **结果预期**：把"装好的样子"**画出来/量出来**，别凭感觉。
5. **最大风险**：最容易翻车的是哪一步？
6. **兜底**：万一不对，能补救/可调吗？

---

## 二、画底板（结构设计）专项清单

### A. 顺序：先定什么（有依赖关系，别跳）
1. **驱动轮直径** → 决定**车轴中心离地高度**（= 半径）
2. **电机安装**：固定孔位/支架 → 决定电机中心高、轮子位置
3. **万向轮总高 = 驱动轮轴心离地高** → **【防翘头】★（这次就栽这）**
4. **轴距**（驱动轴↔万向轮，目标 10~15cm）、**轮距**（两驱动轮间距）
5. **传感位置**：离地 ~1cm、与地面平行(0°)、**贴近驱动轴(5~10cm)**
6. **电池/PCB 位置** → 重心尽量低、**电池压在驱动轴上方**
7. **底板外形 + 安装孔**（对齐电机支架、PCB 孔、传感支架、铜柱）
8. **配套件清单**（见 C）
9. **加工方式**：亚克力切割 / 3D 打印 / 直接用 PCB 当底板（重量、强度、成本）

### B. 必查项（逐条打勾）
- [ ] **三点着地**：前万向轮 + 后两驱动轮 **都着地**、车不摇
- [ ] **万向轮高度 = 驱动轮半径** → 车**水平、不翘头**（★核心）
- [ ] 传感：离地 ~1cm、**与地面平行**、靠近驱动轴
- [ ] 重心低；**电池在底层、压驱动轴**
- [ ] 电机/轮子/万向轮 **不打架**、不挡传感视线
- [ ] **配套件齐**：螺丝、铜柱、**电机线**、连接器、扎带/热缩管
- [ ] **装配顺序**能装得上、也能拆下维修
- [ ] 下载口/开关/充电 位置方便

### C. 配套耗材清单（下单前必查，这次漏了电机线）
| 类别 | 要确认的 |
|---|---|
| 结构 | 螺丝(M2/M3)、螺母、**铜柱**、底板材料 |
| 电机 | **电机线/延长线**、编码器连接器(6pin)、固定支架 |
| 传感 | 传感支架、排线、**电位器调节工具** |
| 电源 | 电池、DCDC/LDO、**开关**、XT30/接线端子 |
| 电路 | PCB 连接器(排针/母座)、杜邦线、焊锡 |

---

## 三、"下单前"最后一遍（别急着点购买/发板）
- [ ] 所有**尺寸量过/算过**（不是猜的）
- [ ] 所有件列了**清单**，缺的**一次性补齐**
- [ ] 脑子里/纸上**过一遍"装好的样子"**，有没有明显不对
- [ ] 有没有**可调/平替**方案（如万向轮高度用垫片可调、孔位留可调余量）
- [ ] **量三遍、切一次**（画板/切割同理：先出图核对，再下单）

---

## 四、写代码前专项（顺带）
- [ ] 这个功能的**输入/输出**是什么？（谁给我数据、我控制谁）
- [ ] **引脚/外设**够不够？会不会和别的冲突？
- [ ] **参数**从哪来（宏/在线调参）？
- [ ] 怎么**验证**它对不对（串口打印？现象？）
- [ ] 改动会不会**破坏已验证的部分**？

---
*本文档是"防返工"机制，每次动手前过一遍。*

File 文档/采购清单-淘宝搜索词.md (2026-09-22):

# 采购清单 · 搜索词版（2026-09-16）

> 配套 `新车设计书.md` §八 + `BOM_Board1_Schematic2_2026-09-16.xlsx`（立创EDA 导出）。
> **板上小件强烈建议走立创商城「BOM 配单」**：上传那个 xlsx → 按 C 编号自动匹配 → 封装 100% 对得上，
> 正好解决"淘宝买错封装焊不上去"的问题，还能和 PCB 一起寄。淘宝留给五金、模块、线束。
> **★ 铁律：板上凡是"母座"，都必须配对应的"公头线"**（XH2.54 2P ×4、PH2.0 6P ×2、8路 10P）。

---

## A. 板上件（优先立创按编号买；淘宝搜索词附后）

| 名称 | 参数 | 封装 | 立创编号 | 淘宝搜索词 | ⚠️ 别买错 |
|---|---|---|---|---|---|
| XH2.54 2P 母座 ×4 | 3.3V / 5V / UART / VM | 直插 2.5mm | C54905973 | `XH2.54 2P 直插 母座` | 要配公头线 |
| 无源蜂鸣器 | QMB-09B-03，2.7kHz | 直插 φ9 / 脚距 4mm | C96256 | `无源蜂鸣器 9*5.5 2.7kHz 脚距4mm` | **别买"有源"** |
| 100nF 电容 | 50V X7R | **0805** | C5137467 | `0805 100nF 50V X7R` | 不是 0603 |
| 1N4148W | 100V/150mA | **SOD-123** | C7420318 | `1N4148W SOD-123 贴片` | 别买 DO-35 直插玻璃管 |
| 排针 1×20 ×2 | 焊到核心板上 | 直插 2.54 | C54950616 | `2.54 单排针 1*20` | **单排**，不是双排 |
| 排母 1×20 ×2 | 核心板插座 | 直插 2.54 | C54973833 | `2.54 单排母 1*20` | 同上 |
| 排母 1×8 ×3 | MPU6050 + TB6612 两排 | 直插 2.54 | C54973824 | `2.54 单排母 1*8` | — |
| 排母 2P ×3 | LED1~3 | 直插 2.54 | C54973825 | `2.54 单排母 1*2` | 看 LED 线头选公/母 |
| PH2.0 6P 母座 ×2 | 电机口 | 直插 **2.0mm** | C54905987 | `PH2.0 6P 直插 母座` | 是 2.0 不是 2.54 |
| 排针 1×10 | 8 路接口 | 直插 2.54 | C54950598 | `2.54 单排针 1*10` | 板上若是弯针就搜"弯针" |
| SS8050 | NPN 三极管 | **SOT-23** | C7420370 | `SS8050 SOT-23 贴片` | 别买 TO-92 直插 |
| 1kΩ | 0603 | **0603** | C2907002 | `0603 贴片电阻 1kΩ` | 别买 0805 |
| 10kΩ | 0603 | **0603** | C2930027 | `0603 贴片电阻 10kΩ` | 别买 0805 |
| 轻触开关 | KH-6X6X5H | **贴片 4 脚 6×6×5** | C2837531 | `6*6*5 贴片轻触开关 4脚` | 别买直插 / 2 脚 |
| TVS 6V | PTVS6V0S1UR 单向 | **SOD-123** | C18723426 | `PTVS6V0S1UR SOD-123` | 单向 6V |

> 注：板上元件位号用的是网名（3.3V / 5V / URAT / VM），丝印会照印——接线时反而直观；`URAT` 是 `UART` 的笔误，不影响功能。

---

## B. 板外件（淘宝）

| 件 | 淘宝搜索词 | 规格要点 |
|---|---|---|
| 60mm 麦轮 ×2 | `60mm 麦轮 全向轮` | 装 **0°**；裸高 3.0cm，配 3mm 垫片凑 3.30 |
| M3 双通铜柱 | `M3 铜柱 双通` | **20/25/30/33mm 各 4 + 5mm ×4**（PCB 抬高）|
| M3 垫片套装 | `M3 垫片 0.5 1 2 3mm 套装` | 各 20 片 |
| M3 螺丝螺母 | `M3 304 螺丝螺母套装` + `M3 尼龙锁紧螺母` | 6~20mm 混装 |
| 小体积降压模块 | `MINI360 降压模块 可调` / `MP1584 降压模块` | ≥2A；**上电前先调到 5.0V 再接板** |
| 电源开关 | `船型开关 KCD1 6A` | ≥5A，串电池正极 |
| XT30 插头 | `XT30 公母插头 带线` | 一对 |
| **XH2.54 公头线** | `XH2.54 2P 单头线` | **4 条**（配板上 4 个 2P 母座）|
| **PH2.0 6P 公头线** | `PH2.0 6P 双头线` / `PH2.0 转 XH2.54 6P 线` | **2 条**（配电机口）|
| 8 路排线 | `2.54 10P 母头 杜邦线` | 配板上 10P 排针 |
| 杜邦线 | `杜邦线 母母 2.54 套装` | 调参 / 飞线 |
| 亚克力底板 | `亚克力激光切割 代加工 3mm` | 按 `底板布局草案.md` §四 孔位清单出图 |
| 传感支架材料 | 同上（用切割边角料） | 高 2.3cm，模块无支架需自制 |
| MPU6050 | `GY-521 MPU6050 模块` | 8 脚；**AD0 接 GND**（地址 0x68）|
| TB6612 | `TB6612FNG 电机驱动模块` | 两排 8 脚，与板上两排 8P 排母对得上 |
| HC-05（若还没有） | `HC-05 蓝牙模块 带底板` | 与 USB-TTL 二选一插 |
| 扎带 / 热缩管 | `尼龙扎带 2*100` / `热缩管套装` | — |
| 核心板（若要换新） | `STM32F103C8T6 核心板` | 必须确认 **PB8/PB9 正常**（旧板那两脚坏）|

---

## C. 你已解决 / 已有（不用买）

- **大电容**（VM 100~470µF、5V/3.3V 各 10µF+0.1µF）→ 你自己解决（手焊并在对应 2-pin 连接器焊盘背面）
- **LED 灯珠 + 限流电阻** → 你已找好（PC13 那颗用 4.7k）
- 已拥有：2× JGA25-370 电机、8 路红外模块、7.4V 电池+充电器、TB6612（确认一下）、核心板

---

## E. 淘宝实查结果（2026-09-16，用你 Edge 的淘宝会话实搜）

| 件 | 搜到的可用选项 | 价格 | 判断 |
|---|---|---|---|
| 无源蜂鸣器 | `9024 一体无源交流蜂鸣器`（φ9.4×2.4mm，脚距 4mm，16Ω，3~5V）；另有 `9*5.5 脚距4mm` 款 | ¥0.29~0.44/个 | ✅ 与封装 BD9.0-P4.00 兼容；**必须"无源"+"电磁式16Ω"+"脚距4mm"** |
| 1N4148W | `原装正品 1N4148W 丝印T4 SOD-123 100V/150mA 20只` | ¥1.98/20只 | ✅ 型号封装完全对 |
| SS8050 | `原装 SS8050 SOT-23 丝印Y1 一件=50个`；散卖 ¥0.03~0.04 | ¥2.5/50个 | ✅ 选丝印 Y1 的 SS8050；**别买 TO-92 直插** |
| 轻触开关 | `6*6*5 贴片轻触开关 4脚`（多规格可选） | ¥0.01~2.13/个 | ✅ 选**贴片立式 4 脚**（脚距 4.5mm）；**别买直插款** |
| XH2.54 2P 母座 | `XH2.54 2P 直插 母座/直针座` | ¥0.02~0.08/个 | ✅ **别买"卧贴/立贴"**（那是贴片） |
| PH2.0 6P 母座 | `PH2.0mm 直针座 母座 2P~16P` | ¥1.25~2.38/件 | ✅ 2.0mm 间距；同样只买直针座 |
| 2.54 单排母/排针 | `2.54mm 单排母/单排针 1*2P~40P` | ¥0.03~0.05/个 | ✅ **必须单排**；别买"双排 2*20"（核心板两条独立 1*20，行距 12.8mm 固定） |
| 60mm 麦轮 | `麦克纳姆轮 60mm 全向轮`（多为左/右旋成对卖） | ¥4~8.5/个（品牌款 ¥23~33） | ✅ 买一对、用一个备一个；当被动随动轮用，左右旋都行 |
| M3 五金 | `铜柱螺丝包 9种/12种 M3*5~16 双通+螺母`、盒装套装 | ¥6.36~19.19 | ✅ 一次买齐；⚠️ **套装多为 5~20mm，前支撑要的 25/30/33mm 长铜柱需单独买** |

**仍需自己搜（还没实查，都是标准件、风险低）**：`M3 垫片 0.5 1 2 3mm 套装`、`M3 尼龙锁紧螺母`、
`0603 0805 贴片电阻电容 样品本`、`PTVS6V0S1UR`(或 `SOD-123 6V 单向 TVS`)、
`XH2.54 2P 单头线`、`PH2.0 6P 双头线`、`2.54 10P 杜邦线`、`MINI360 降压模块`、`船型开关 KCD1 6A`、`XT30 公母`、
`GY-521 MPU6050 模块`、`TB6612FNG 模块`、`亚克力激光切割 3mm`、`杜邦线/扎带/热缩管`。

---

## F. 加购进度（2026-09-16，我代操作淘宝加入购物车）

**✅ 已加入购物车（12 件，合计约 ¥107）**：
1. 1N4148W SOD-123 20只 ¥1.98（优信电子）
2. SS8050 SOT-23 50个 ¥2.5（华能盛，国产 SS8050 Y1 50个）
3. 无源蜂鸣器 YS-MBZ9042C05R42 9×4.2mm 脚距4mm 电磁式 5V ¥0.6（亿利科技）
4. 6×6×5 贴片轻触开关 7 种装共 70 个 ¥8.48（MCUNODE）
5. XH2.54 2P 直针母座 10个 ¥1.5（有成为）
6. PH2.0 6P 直针母座 10个 ¥1.5（clb2356）
7. **XH2.54 2P 单头线 20CM（10条）**（Zave）
8. **M3 910PCS 铜柱内六角螺丝螺母盒装**（6/8/10/12/14mm）¥35（壹优创）
9. **PH2.0-6P 双头同向 20CM（5条）** ¥2.9（电子爱好者之家）
10. **2.54 单排排针/排母 8种120个混装套装** ¥23（QBVDIY）
11. **60mm 麦轮 带黑轮毂 一套4个（2左+2右）** ¥25.6（欣薇电子）
12. **GY-521 MPU6050 模块**（欣薇，沉金板镀金/焊直针向下）¥4.1
13. **TB6612FNG 电机驱动模块**（欣薇，规格：TB6612FNG 焊好排针）¥2.1 —— ⚠️ 该店标"排针孔距 15mm"，**到货先对一下与你板上两个 1×8 排母（间距 12.8mm?）是否一致**，不一致可用杜邦线飞接
14. **HC-05 蓝牙模块（主从一体）**（鹿小班，【实验专用】原装款）—— ⚠️ 选"原装"后页面价跳到 **¥45**（可能选贵了）；想省钱可在购物车里换成"兼容HC-05"（约 ¥5）或 JDY-31
> ⚠️ 付款前清理：① 误加了一件 **PH2.0 5P**（10个）→ 删；② 上面 HC-05 若显示 ¥45，按需保留或换款（麦轮只加了一套，无重复）

**⏳ 剩下这几件没加（都是"随便一家都能买"的标准件，点开→选规格→加购，1 分钟一件）**：

| 件 | 搜索词 | 规格 |
|---|---|---|
| M3 垫片 | `M3 垫片 0.5 1 2 3mm 套装` | 各 20 片 |
| M3 尼龙锁紧螺母 | `M3 尼龙锁紧螺母` | 麦轮当轴用 |
| 杜邦线/扎带/热缩管 | `杜邦线 母母 2.54 套装` 等 | — |
| 10P 排线 | `2.54 10P 母头 杜邦线` | 排针排母套装里含 40P 可掰，可选 |

**◻ 可选件（按实际情况，不买也能跑）**：
- **电源开关 KCD1 ≥5A**：= 总电源开关，串电池正极；旧车已有 / 不介意拔插头 → **可不买**（但"能断电"这件事不能省）
- **XT30 公母带线**：= 电池接头；**先看电池现在是什么插头**（自带 XT30 且有配对 → 不买；T 插/XT60/JST → 买对应款或转接）

**✅ 已有 / 不用买**：降压模块、亚克力底板、U5（PTVS6V0S1UR，板上 TVS 防浪涌）、电机、8 路红外模块、电池、核心板、**麦轮/MPU6050/TB6612/HC-05（旧车已有）**

### F2. 2026-09-16 补加（蜂鸣器电路小元件）
- [x] **0603 贴片电阻 1K**（100个，5%）— 鹏茂科技
- [x] **0603 贴片电阻 10K**（100个，5%）— 鹏茂科技
- [x] **0805 100nF 50V X7R 贴片电容**（50只，三星 CL21B104KBCNNNC；BOM 同款富捷 FCC0805B104K500DT 亦可）— 佳信源
> ⚠️ 付款前删：误加了一件 **1R 0603 电阻**（点错阻值）；另仍需改 **PH2.0 母座 5P→6P**、**XH2.54 2P 线 5CM→20CM**

### F3. ★前支撑改"球脚轮"（2026-09-16 定，替代麦轮）
**尺寸算法**：总高 = 球脚轮裸高 + 铜柱/垫片堆叠 = **3.30cm**，且堆叠只能加不能减 →
**球脚轮裸高必须 ≤ 33mm，且尽量接近 33mm**（33 − 最长铜柱14 ≈ 19mm 起，但太矮要垫很多）。
**推荐：球径 20~25mm 的法兰式万向球（牛眼轮），总高约 26~31mm**，配 2~8mm 铜柱/垫片凑 3.30 ✅
**别买**：球径 ≥30mm（总高 >34mm 矮不下来）、螺杆式/弹簧式（没法接铜柱）。
**装配**：其法兰孔距（20~30mm）与底板 z=±3.0cm 两孔对不上 → 做一块 **30×30mm 小转接板**（亚克力边角料/废PCB）：两孔对底板 ±3.0，球脚轮拧在板下，中间夹铜柱堆叠调高度。

---

## D. 下单/收货后必查（照 `动手前考虑清单`）

- [ ] 电机 6P 线：确认两头规格（板上 PH2.0 ↔ 电机端）
- [ ] 板子到货：目视 → 万用表测 5V/GND 是否短路 → 上电测 7.4V/5V/3.3V → **最后才插核心板**
- [ ] 核心板排母 1 脚方向（方焊盘）与核心板 1 脚对齐，插前确认 5V/GND 脚位
- [ ] 小降压模块先调到 5.0V 再接板

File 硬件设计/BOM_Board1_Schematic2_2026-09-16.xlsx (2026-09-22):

No. | Quantity | Comment | Designator | Footprint | Value | Manufacturer Part | Manufacturer | Supplier Part | Supplier
1 | 4 | LAIL-PHC2.54-2P-01-XH-L | 3.3V,5V,URAT,VM | CONN-TH_2P-P2.50_HC-XH-2A-G |  | LAIL-PHC2.54-2P-01-XH-L | LAILAN(莱联) | C54905973 | LCSC
2 | 1 | 2.7kHz | BUZZER1 | BUZ-TH_BD9.0-P4.00-D0.6-FD | 2.7kHz | QMB-09B-03 | 华能 | C96256 | LCSC
3 | 1 | 100nF | C2 | C0805 | 100nF | FCC0805B104K500DT | FOJAN(富捷) | C5137467 | LCSC
4 | 1 | 1N4148W | D2 | SOD-123_L2.7-W1.6-LS3.7-FD |  | 1N4148W | R+O(宏嘉诚) | C7420318 | LCSC
5 | 2 | LAIL-PZ2.54-20P-L | H1,H2 | CONN-TH_LAIL-PZ2.54-20P-L |  | LAIL-PZ2.54-20P-L | LAILAN(莱联) | C54950616 | LCSC
6 | 3 | LAIL-PM2.54-2P-L | LED1,LED2,LED3 | HDR-TH_2P-P2.54-V-F |  | LAIL-PM2.54-2P-L | LAILAN(莱联) | C54973825 | LCSC
7 | 2 | LAIL-PHC2.0-6P-01-PH-L | MOTOR1,MOTOR2 | CONN-TH_6P-P2.00_HDGC2008WV-06P |  | LAIL-PHC2.0-6P-01-PH-L | LAILAN(莱联) | C54905987 | LCSC
8 | 3 | LAIL-PM2.54-8P-L | MPU6050,U3,U4 | HDR-TH_LAIL-PM2.54-8P-L |  | LAIL-PM2.54-8P-L | LAILAN(莱联) | C54973824 | LCSC
9 | 1 | SS8050 | Q1 | SOT-23-3_L2.9-W1.3-P1.90-LS2.4-BR |  | SS8050 | R+O(宏嘉诚) | C7420370 | LCSC
10 | 1 | 1kΩ | R1 | R0603 | 1kΩ | FRC0603F1001TS | FOJAN(富捷) | C2907002 | LCSC
11 | 1 | 10kΩ | R2 | R0603 | 10kΩ | FRC0603J103 TS | FOJAN(富捷) | C2930027 | LCSC
12 | 2 | LAIL-PM2.54-20P-L | stm321,stm322 | HDR-TH_LAIL-PM2.54-20P-L |  | LAIL-PM2.54-20P-L | LAILAN(莱联) | C54973833 | LCSC
13 | 1 | KH-6X6X5H-STM | SW1 | SW-SMD_4P-L6.0-W6.0-P4.50-LS9.0_H5.0 |  | KH-6X6X5H-STM | kinghelm(金航标) | C2837531 | LCSC
14 | 1 | PTVS6V0S1UR | U5 | SOD-123_L2.7-W1.6-LS3.7-RD |  | PTVS6V0S1UR | FUXINSEMI(富芯森美) | C18723426 | LCSC
15 | 1 | LAIL-PZ2.54-10P-W | UH1 | HDR-TH_10P-P2.54-H-M-W9.9_BX |  | LAIL-PZ2.54-10P-W | LAILAN(莱联) | C54950598 | LCSC

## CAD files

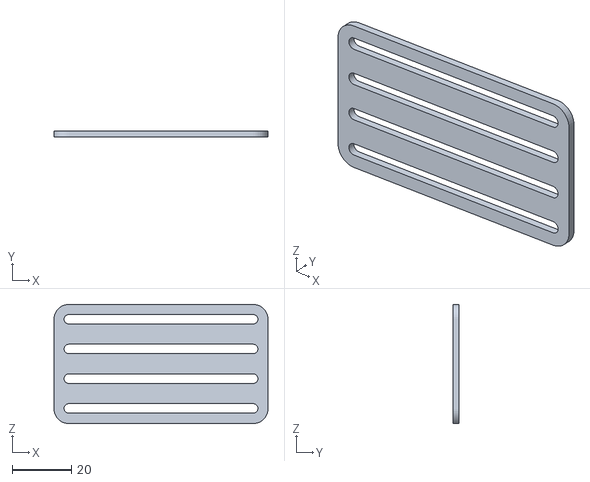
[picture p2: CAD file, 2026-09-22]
机械结构/零件2拓展板.STL
72.0 x 2.00 x 40.1

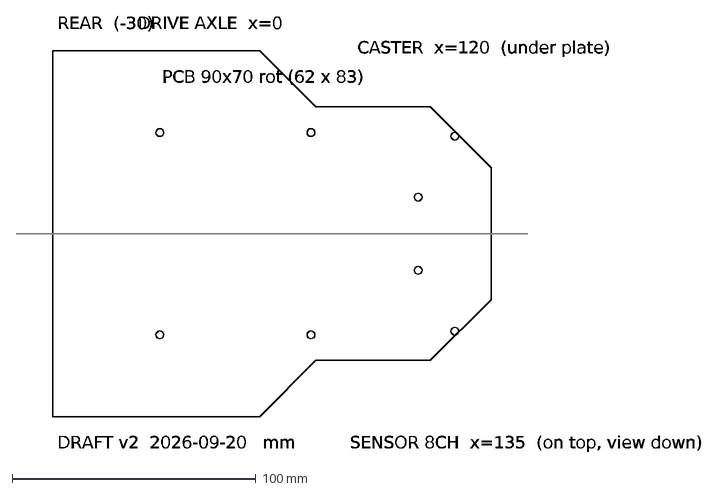
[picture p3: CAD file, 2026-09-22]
机械结构/新底板-草案.dxf
REAR (-30)
DRIVE AXLE x=0
PCB 90x70 rot (62 x 83)
CASTER x=120 (under plate)
SENSOR 8CH x=135 (on top, view down)
DRAFT v2 2026-09-20 mm

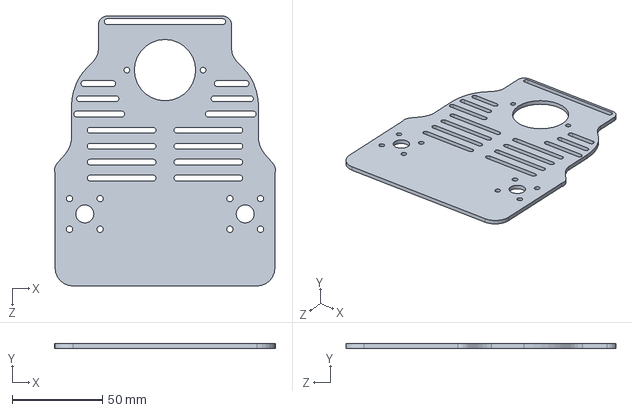
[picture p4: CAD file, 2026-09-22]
机械结构/零件1.SLDPRT
122.7 x 2.50 x 149.8 mm

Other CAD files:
机械结构/零件2.SLDPRT
机械结构/零件2.STL

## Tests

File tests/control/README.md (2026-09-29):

# 主控制宿主回归

运行 `powershell -ExecutionPolicy Bypass -File tests/control/run.ps1`。

测试直接包含实际 `line_follow.c`，链接实际 `filter.c` 和 `pid.c`，仅模拟红外、陀螺、测速、编码器、串口和电机硬件接口。覆盖单拍丢线恢复、旋转找线及恢复时的历史清理、十字强制直行、葫芦圈连续离开判据和停车遥测一致性。

脚本分别编译默认对称转向记忆及 `USE_SYMMETRIC_CORR_TRIM=0` 回退分支，两种配置各运行五个用例。回退配置只在测试翻译单元内覆盖，不改写工程的 `app_config.h`。

这些测试验证软件状态与输出，不模拟车辆动力学，不代表实车已经通过葫芦圈。编译器固定为本机 RedPanda-Cpp 的 MinGW64 GCC；换电脑可调整脚本中的编译器目录。

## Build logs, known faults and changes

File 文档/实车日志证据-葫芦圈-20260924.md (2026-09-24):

# 实车日志证据：葫芦圈（FW:0924-2615）

日期：2026-09-24 晚
用户反馈原话：**"成功了一次，但不稳定"**
软件：`FW:0924-2615`（长按出发/短按暂停；KP 2.5 / KD 1.1；速度 34/24/30；
      相切点识别用 1kHz maxraw；`GOURD_FLIP_ON_NORMAL 0`；里程出圈 24847mm）

> 这是本项目**第一次拿到葫芦圈那一段的真实串口数据**。以下三条结论全部由它推出，
> 不再是猜测。

---

## 证据 ①：陀螺量程在**削顶**（GZ 被钉在 −247）

```
FW:0924-2615 ST=2 IR:00011000 RPM1=14 RPM2=127 OD=1075 GZ=-247 GW=0 IG=1 K1=6
FW:0924-2615 ST=2 IR:00001100 RPM1=14 RPM2=156 OD=1228 GZ=-247 GW=0 IG=1 K1=0
FW:0924-2615 ST=2 IR:00111100 RPM1=14 RPM2=113 OD=1236 GZ=-247 GW=0 IG=1 K1=7
FW:0924-2615 ST=2 IR:00110000 RPM1=14 RPM2=156 OD=1318 GZ=-228 GW=0 IG=1 K1=1
FW:0924-2615 ST=2 IR:00011000 RPM1=0 RPM2=99  OD=1435 GZ=-247 GW=0 IG=1 K1=0
FW:0924-2615 ST=2 IR:00001110 RPM1=14 RPM2=213 OD=1570 GZ=-247 GW=0 IG=1 K1=0
FW:0924-2615 ST=2 IR:00011000 RPM1=14 RPM2=71 OD=1583 GZ=-247 GW=0 IG=1 K1=6
FW:0924-2615 ST=2 IR:00110000 RPM1=0 RPM2=113 OD=1593 GZ=-247 GW=0 IG=1 K1=0
FW:0924-2615 ST=2 IR:00011000 RPM1=0 RPM2=170 OD=1890 GZ=-247 GW=0 IG=1 K1=0
FW:0924-2615 ST=2 IR:00110000 RPM1=14 RPM2=142 OD=1903 GZ=-247 GW=0 IG=1 K1=0
FW:0924-2615 ST=2 IR:00000111 RPM1=312 RPM2=312 OD=2972 GZ=-247 GW=2 IG=1 K1=1
FW:0924-2615 ST=2 IR:00001100 RPM1=270 RPM2=312 OD=3018 GZ=-247 GW=2 IG=1 K1=5
FW:0924-2615 ST=2 IR:00110000 RPM1=199 RPM2=28  OD=3056 GZ=-247 GW=2 IG=1 K1=5
```
（日志里 `GZ=-247` 出现了**十几次**，还出现过 `GZ=+250`）

**判读**：`±250 dps` 档的满量程 = `32767 / 131 ≈ 250`。
**反复出现同一个值 = 削顶的签名**（真实测量不会反复落在同一个数上）。

⇒ `GYRO_CONFIG(0x1B)` 的写入**没生效**，芯片留在 **±250°默认档**。
⇒ 车转速一超过 250°/s，读数就被钉住 → **航向角积分少算** →
   出圈"转到 85°"实际会转过头。
⇒ 历史上一串"转过头 / 转不够"的抱怨，根子有一部分在这里。

---

## 证据 ②：`GW` **永远到不了 3** —— 是被"IG 抖动"抹掉的

```
FW:... OD=2127 GZ=-183 GW=0 IG=1     ← 起
FW:... OD=2151 GZ=89   GW=0 IG=1
FW:... OD=2188 GZ=15   GW=1 IG=1     ← 数到 1
FW:... OD=2209 GZ=-220 GW=1 IG=1
FW:... OD=2247 GZ=-247 GW=1 IG=1
...
FW:... OD=2863 GZ=119  GW=1 IG=1
FW:... OD=2918 GZ=-161 GW=1 IG=1
FW:... OD=2972 GZ=-247 GW=2 IG=1     ← 数到 2
GOURD-ENTRY mark cleared (left gourd, back on plain line)
FW:... OD=3121 GZ=85   GW=0 IG=0     ← ★被抹回 0！永远到不了 3
```

而且整份日志里 `GOURD-ENTRY mark set` / `mark cleared` **交替出现很多次**
（`IG` 在 0/1 之间一秒内反复跳）—— 这就是队友文档里写的"`IG` 乱跳"。

**判读**：相切点**识别得到**（能数到 1、2），
但上一版按队友方案加的 **"`IG=0` 立刻清零 `GW`"** 把它抹掉了 →
`GW` 永远凑不到 `GOURD_TOTAL=3` → 永远不归 0 → **出圈永远不触发**。

⇒ 这是**上一版改动引入的问题**，不是识别问题。

---

## 证据 ③：里程阈值 24847mm **在这条赛道上根本到不了**

```
FW:... OD=7332 IR:00000000 RPM1=255 RPM2=412 GZ=-20 GW=0 IG=0
FW:... OD=7800 IR:00000000 RPM1=113 RPM2=113 GZ=1   GW=0 IG=0
```

整趟日志里 `OD` 最大只到 **~7800mm**，而里程出圈阈值是 **24847mm**。

⇒ **里程出圈永远不可能触发。** 这个数（当初在另一条路线/另一次测量下得到的）
  与现在的赛道对不上。

---

## 顺带看到、但本版没动的两件事

### A. 丢线兜底没起作用，车直着开出了赛道
日志末尾：`IR:00000000`（**全灭**）持续很久，而两轮转速还在 **~130 RPM 直行**，
`OD` 从 7332 一路涨到 7800+。

按设计，持续丢线超过 `LOST_SPIN_DELAY(2)` 拍就该**原地旋转找线**，
超过 `LOST_MAX_CYCLES(150)` 就该**停车防跑飞**。
但日志里车在直行 —— **兜底没生效**。这是一个独立问题，值得单独查。

### B. `BRANCH #1..#20` 大量出现
整趟里 `BRANCH #n ... -> NOT cross (turn)` 出现了 **20 次**，而 `CROSS` 只中 **1 次**。
分支判据用的特征（"宽图案 + 只贴一端"）与相切点判据①**是同一个特征** ——
它在葫芦圈这一段**极其常见**，这正是相切点判据容易误报的结构性原因。

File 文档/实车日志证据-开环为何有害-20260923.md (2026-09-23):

# 实车日志证据：开环方案为何有害（2026-09-23）

> 来源：用户实跑日志，固件 `FW:0923-1800`（**已删除的"葫芦圈编码器开环"方案**）。
> 这份日志在开环方案被删除**之后**才拿到 —— 但它恰好**证明了删掉是对的**。
> ⚠️ 以后想再给葫芦圈加"开环/盲走"的人：**先读完这份日志**。

---

## 一、日志原文（22 拍，20Hz）

```
FW:0923-1800 IR:00001110 DG=2 MR=01 G=0   RPM1=150 RPM2=71
FW:0923-1800 IR:00001100 DG=2 MR=01 G=0   RPM1=150 RPM2=59
FW:0923-1800 IR:00011000 DG=2 MR=01 G=0   RPM1=145 RPM2=59
FW:0923-1800 IR:00011000 DG=2 MR=01 G=0   RPM1=142 RPM2=76
FW:0923-1800 IR:00011100 DG=2 MR=01 G=0   RPM1=136 RPM2=108
FW:0923-1800 IR:00001100 DG=2 MR=01 G=0   RPM1=130 RPM2=108
FW:0923-1800 IR:00000110 DG=2 MR=11 G=0   RPM1=127 RPM2=93
FW:0923-1800 IR:00000110 DG=2 MR=11 G=0   RPM1=136 RPM2=76
FW:0923-1800 IR:11100110 DG=2 MR=11 G=250 RPM1=139 RPM2=76    ← ★开环触发
FW:0923-1800 IR:00111110 DG=2 MR=01 G=250 RPM1=116 RPM2=82
FW:0923-1800 IR:00001111 DG=1 MR=00 G=1   RPM1=110 RPM2=82    ← 开始盲走
FW:0923-1800 IR:00000111 DG=1 MR=10 G=1   RPM1=125 RPM2=65
FW:0923-1800 IR:00000111 DG=1 MR=10 G=2   RPM1=136 RPM2=56
FW:0923-1800 IR:00000011 DG=1 MR=10 G=2   RPM1=90  RPM2=88
FW:0923-1800 IR:00000001 DG=1 MR=10 G=2   RPM1=65  RPM2=116
FW:0923-1800 IR:00000000 DG=1 MR=11 G=3   RPM1=65  RPM2=116   ← ★★ 全灭 = 丢线
FW:0923-1800 IR:00000000 DG=1 MR=11 G=3   RPM1=93  RPM2=79
FW:0923-1800 IR:00000000 DG=1 MR=11 G=4   RPM1=116 RPM2=59
FW:0923-1800 IR:00000000 DG=1 MR=11 G=4   RPM1=88  RPM2=93
FW:0923-1800 IR:00000000 DG=1 MR=11 G=5   RPM1=62  RPM2=119
FW:0923-1800 IR:00000000 DG=1 MR=11 G=5   RPM1=42  RPM2=136
```

位序：**位图第 0 个字符 = 最左那一路(L1)**；权重 `-7 -5 -3 -1 +1 +3 +5 +7`
状态：`G=0` 正常巡线　`G=250` 开环的"直行补偿前瞻"　`G=1..5` 开环动作序列第几段

---

## 二、逐拍解析

| 拍 | 位图 | 亮 | error | G | 差速(RPM1−RPM2) | 说明 |
|---|---|---|---|---|---|---|
| 0 | `00001110` | 3 | **+9** | 0 | +79 | 线在右 → 车左转追线 |
| 1 | `00001100` | 2 | **+4** | 0 | +91 | error 在收敛 |
| 2 | `00011000` | 2 | **0** | 0 | +86 | 已追上 |
| 3 | `00011000` | 2 | **0** | 0 | +66 | |
| 4 | `00011100` | 3 | **+3** | 0 | +28 | |
| 5 | `00001100` | 2 | **+4** | 0 | +22 | |
| 6 | `00000110` | 2 | **+8** | 0 | +34 | |
| 7 | `00000110` | 2 | **+8** | 0 | +60 | |
| **8** | `11100110` | 5 | −7 | **250** | +63 | **★开环触发 → 强制直行** |
| 9 | `00111110` | 5 | **+14** | 250 | +34 | **error=+14 要求强左转，却被强制直行** |
| 10 | `00001111` | 4 | **+16** | **1** | +28 | **★盲走。红外还在正常报数！** |
| 11 | `00000111` | 3 | **+15** | 1 | +60 | ★盲走 |
| 12 | `00000111` | 3 | **+15** | 2 | +80 | ★盲走 |
| 13 | `00000011` | 2 | **+12** | 2 | +2 | ★盲走 |
| 14 | `00000001` | 1 | +7 | 2 | −51 | 只剩最右一路 |
| **15** | `00000000` | 0 | 0 | 3 | −51 | **★★ 全灭 = 丢线** |
| 16-20 | `00000000` | 0 | 0 | 4,5 | ±57~94 | 丢线兜底在甩动找线 |

---

## 三、决定性证据

### 证据 1：**纯 PD 阶段 error 一路在收敛**

```
拍 0-7（G=0，纯 PD）：+9 → +4 → 0 → 0 → +3 → +4 → +8 → +8
```
**没有发散，一直在跟线。** 这正是队友文档里"通用 PD 就正确进了下一个圆"的实车复现。

### 证据 2：**开环在"红外还看得见线"的时候就接管了**

拍 10~13 的红外**明明还在报 error = +16 / +15 / +15 / +12**（要求强左转），
但 `G=1/2` = 开环盲走，**把这些指令全部丢弃** → 车照直走 → 第 15 拍全灭。

**如果这四拍交给 PD**：error 从 +16 降到 +12 —— **正在收敛的路上**。

### 证据 3：**触发时刻决定成败 → 这就是"有时候没问题"的原因**

- 触发时车身正好对齐 → 盲走可能"碰巧"走对
- 触发时车身偏着（如本日志拍 8）→ 盲走直接冲出去

用户原话"**有时候是没有问题的，有时候会直直的开出去**" —— 完全对上。

---

## 四、结论

**开环方案不是"没用"，是"有害"**：它把一个**本来在正常工作的 PD 控制器强行关掉**，
换成一段不受任何反馈约束的盲走。

**正确做法**：
1. 葫芦圈内**交给 PD**（不给它加任何开环动作）
2. 只在**真正的出口**做那一下转向（本条日志里没走到出口就丢线了）
3. 把力气花在**不干扰 PD** 上：
   - 圈内屏蔽丢线兜底（防被拽走）
   - 单路掉路容忍（相切处最边传感器熄灭时别丢转向力度）
   - 后半段减速（让 PD 跟得上曲率突变）

---

## 五、次要发现：两轮转速明显不平衡

```
RPM1（左轮）多在 130~150
RPM2（右轮）多在 56~108      ← 右轮慢很多
```

旧固件**没开速度闭环**，所以这是开环 PWM 下两电机的固有差异。
新固件已开 `USE_SPEED_LOOP=1`，正好能治这个 —— **但 PID 需要整定**。

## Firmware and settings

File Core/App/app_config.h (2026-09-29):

#ifndef APP_CONFIG_H
#define APP_CONFIG_H

/* ============================================================================
 *  app_config.h  —  重制版智能车「配置中心」
 *  唯一需要改参数/改接线的入口。分层原则：
 *     - 逻辑参数/调参         → 改这里
 *     - 物理引脚(电机/循迹/人机) → 由 CubeMX 的 main.h / gpio.c 管理(硬件层)
 *     - 新传感器(IMU 等)      → 打开 USE_* 开关 + 在 CubeMX 配好对应外设 + 填引脚
 *
 *  ★ 2026-09-20：CubeMX 已按新车重配（8 路循迹 / TIM3+TIM4 编码器 / PA11 蜂鸣器 PWM /
 *    PB9 启动键 / PC13+PB14+PB15 三灯），并已重新生成 + 编译核验。
 *  ★ 本车是"复刻学长的车"：传感中心距驱动轴 213mm（旧车 50mm）→ 几何增益约 4.3 倍，
 *    KP / 速度阈值都必须比旧车小很多。旧车实测 KP=10、SP=40 只能当"上限参考"。
 * ==========================================================================*/

/* 0929-R1：保留 G40 的直/弯道速度、PD、速度环参数及左右补偿。
 * 本次修正转向记忆左右不对称、丢线恢复历史、进圈连续计数和编码器回绕。
 * 以下历史调参记录仅作参考；增量式 PID 并不天然免饱和或限制输出变化率。
 * 保留原有电机补偿和输出下限；累计路程硬转默认关闭，需实车另行标定。
 */
#include "main.h"      /* 提供引脚标签(LINE_1_Pin、LED1_Pin 等), main.h 内含 stm32f1xx_hal.h */
#include <stdint.h>

/* ---------------------------------------------------------------------------
 * 一、功能开关（新车第一次上车都关着，跑通一个开一个）
 * -------------------------------------------------------------------------*/
/* ★★★ 临时测试开关（2026-09-20）★★★
 *   0 = 正常模式：按启动键 → 3 秒读秒 → 开跑；长按 1 秒 = 急停   ← 【当前】
 *   1 = 临时模式：上电自动读秒 3 秒开跑（禁用按键）—— 只在核心板按键坏时用
 *   （2026-09-20 曾因老板子 PB9 坏置 1；当晚换上好板子后已改回 0）
 *   ⚠️ 置 1 时：上电 3 秒后车就会动，调试全程架空或手按着电源！ */
#define AUTO_START_ENABLE    0

#define USE_ENCODER          1   /* 1=用 JGA25 编码器测速(TIM3/TIM4 已配成正交解码; 手转一圈核对 422)
                                     ★ 只影响测速读数, 闭环仍由 USE_SPEED_LOOP 决定 */
#define USE_IMU              1   /* ★2026-09-22 启用 MPU6050：I2C2(PB10/PB11)，驱动手写在 Core/Src/i2c.c */
/* ★2026-09-23 晚 21:3x 【重新打开】速度闭环 —— 用户说"速度闭环你先测试"
   （KP 已经按实测从 3.0 降到 2.0，甩头明显减轻 → 现在轮到闭环这一个变量）
   验证方法（架空、空载）：
       串口发 S 40  → 目标 = 40 × RPM_PER_PWM_X100/100 = 40 × 5.50 = **220 RPM**
       看 RPM1/RPM2 是否都稳在 220 附近（12V 实测 k≈5.5；他们注释里那个 144 是 7.4V 的旧数）
       再发 S 52 → 应稳在 286 附近；抖动/啸叫就把 SPD_PID_KI 减小
   为什么闭环值得开：开环下同样的 SP 在满电/半电跑出来的车速不一样（k 与电池电压成正比）；
       闭环把这个漂移消掉 → ★**提速才能变得可预测**（这也是"先验闭环、再大胆提速"的顺序理由）。 */
#define USE_SPEED_LOOP       1   /* ★2026-09-26 晚：试过 0（关）→ 车没力气还是过不去 → 回到 1。突变改由【增量式 PID】根治，见下 */
/* ★★★ 2026-09-26 晚【改用增量式 PID（用户方案）—— 这是本轮的核心改动】★★★
 *  上面那句"关掉它 → 车没力气"是实测结论（FW:0926-NOSPD）：
 *    直线段 RPM 只有 85，而目标 sp=24 该是 132 RPM —— 命令 24 PWM 却只跑出
 *    15 PWM 的转速（出力只有标定的 62%）。开环下 RPM≈PWM×k 随电压漂，
 *    **速度环本来就是在补偿这个**；关掉它车就没力气，葫芦圈照样过不去。
 *
 *  ⇒ 所以正确做法不是关闭环，而是【换掉 PID 的形式】：
 *     位置式 u = Kp·e + integral + Kd·d + bias   ← integral 会顶满(50) → 满舵突变
 *     增量式 Δu = Kp(e_k−e_{k−1}) + Ki·e_k·dt + Kd(...)，u_k = u_{k−1}+Δu+bias_k
 *   增量式【结构上没有积分累计量】→ 不会饱和；输出只能逐拍变化 → 自带速率限制；
 *   且仍然闭环 → 保住电压补偿。实现见 control/pid.c 的文件头长注释。
 *
 *  黑匣子证据（就是它让"积分顶满"这个结论无可回避）：
 *     T129 PWM= 62/ -4    T131 PWM= 71/ -1    T429 PWM= 85/-18    T433 PWM= 54/ 0
 *     右轮被钉在 −1~−21（倒转）、左轮 66~99，而按 PD 只该给出 ≈−14；
 *     这就是"指令温和、电机满舵" = 用户说的"转向突变"。
 */
#define USE_ADAPTIVE_SPEED   1   /* 1=速度自适应(直道快/弯道慢) */
#define USE_D_FILTER         1   /* 1=误差一阶低通(压 D 项噪声) */
#define D_FILTER_ALPHA       0.5f
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

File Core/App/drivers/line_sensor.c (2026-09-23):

#include "line_sensor.h"
#include "app_config.h"     /* LINE_CHANNELS / LINE_CHANNEL_TABLE / LINE_ACTIVE_LEVEL */
#include "main.h"

/* 循迹通道表(接线顺序 左->右)。改 8 路循迹只改 app_config.h 的 LINE_CHANNELS + 表 */
static const line_channel_t kChannels[LINE_CHANNELS] = { LINE_CHANNEL_TABLE };

/* ============================================================================
 * ★★ 突发过采样（2026-09-23）：在一拍内连读 N 次再表决，提高有效采样频率。
 *    只改本文件，三个调用点（循迹 1 处 + 遥测 2 处）自动受益。
 *    配置见 app_config.h 的 LINE_OS_*。
 * ==========================================================================*/
#if (LINE_OS_SAMPLES < 1) || (LINE_OS_SAMPLES > 64)
#error "LINE_OS_SAMPLES 必须在 1~64"
#endif

/* ---- DWT 周期计数器：给突发采样提供微秒级时间基准 ----
   Cortex-M3 有 DWT->CYCCNT（72MHz 下 1µs = 72 周期）。
   注意：HAL 不会自动使能它，必须自己置 DEMCR.TRCENA 并清 CYCCNT。 */
static uint8_t  dwt_ok    = 0;
static uint32_t us_cycles = 72u;    /* 1µs 对应的 CPU 周期数，初始化时按 SystemCoreClock 重算 */

static void dwt_init(void)
{
  CoreDebug->DEMCR |= CoreDebug_DEMCR_TRCENA_Msk;   /* 使能跟踪/调试模块 */
  DWT->CYCCNT = 0u;
  DWT->CTRL  |= DWT_CTRL_CYCCNTENA_Msk;             /* 使能周期计数器 */
  if (DWT->CTRL & DWT_CTRL_CYCCNTENA_Msk)
  {
    dwt_ok    = 1u;
    us_cycles = SystemCoreClock / 1000000u;         /* 72MHz → 72 */
    if (us_cycles == 0u) us_cycles = 1u;
  }
  else
  {
    dwt_ok = 0u;                                     /* 读不到就退化成"背靠背采样" */
  }
}

/* 忙等 us 微秒。DWT 不可用时退化成空操作（= 背靠背采样，仍能工作，只是间距不可控） */
static void dwt_delay_us(uint16_t us)
{
  uint32_t start, want;
  if ((us == 0u) || (dwt_ok == 0u)) return;
  start = DWT->CYCCNT;
  want  = (uint32_t)us * us_cycles;
  /* 用无符号差值比较 → CYCCNT 回绕(约 59.6s)天然安全 */
  while ((uint32_t)(DWT->CYCCNT - start) < want) { /* spin */ }
}

/* 读一次原始位图（不含任何表决） */
static uint16_t line_raw_once(void)
{
  uint16_t bm = 0u;
  uint8_t  i;
  for (i = 0; i < LINE_CHANNELS; i++)
  {
    if (HAL_GPIO_ReadPin(kChannels[i].port, kChannels[i].pin) == LINE_ACTIVE_LEVEL)
    {
      bm |= (uint16_t)(1u << i);
    }
  }
  return bm;
}

#if LINE_OS_ENABLE
/* ★过采样"有没有起作用"的证据计数器（2026-09-23）
   统计：有多少拍，出现了"同一拍内子采样之间位图不一致"。
   为什么它能当证据：
     · 若红外在这几个µs内完全不变 → 所有子采样位图相同 → 计数器不涨 → 过采样白做
     · 只要它 >0，就说明**单次采样会漏掉的东西被快采样抓到了**（这正是加它的目的）
   增量语义：读一次清一次（telemetry 每 50ms 读一行，正好是"这个窗口内涨了多少"）。 */
static uint32_t os_ticks     = 0;   /* 已过采样的拍数 */
static uint32_t os_disagree  = 0;   /* 其中"子采样位图不一致"的拍数 */
static uint32_t os_disagree_acc = 0;/* 累积值（给"读一次清一次"用） */

/* 突发采样 N 次 → 合成一个位图 */
static uint16_t line_raw_burst(void)
{
  uint8_t  cnt[LINE_CHANNELS];
  uint16_t or_all   = 0u;
  uint16_t and_all  = 0xFFFFu;
  uint16_t bm       = 0u;
  uint8_t  i;
  uint8_t  n;

  for (i = 0; i < LINE_CHANNELS; i++) cnt[i] = 0u;

  for (n = 0; n < (uint8_t)LINE_OS_SAMPLES; n++)
  {
    uint16_t s = line_raw_once();
    or_all  |= s;
    and_all &= s;
    for (i = 0; i < LINE_CHANNELS; i++)
    {
      if (s & (uint16_t)(1u << i)) cnt[i]++;
    }
    /* 最后一次之后不用再等 */
    if ((uint8_t)(n + 1u) < (uint8_t)LINE_OS_SAMPLES) dwt_delay_us((uint16_t)LINE_OS_SPACING_US);
  }

  /* ★证据统计：or != and 就说明这几个子采样之间有一个 bit 变过 */
  os_ticks++;
  if (or_all != and_all) { os_disagree++; os_disagree_acc++; }

#if LINE_OS_VOTE_MAJORITY
  /* 多数表决：亮的路数 >= 半数 才算亮。
     用 cnt*2 >= N 的整数写法，避免浮点。
     好处：单次毛刺不会改变图案 → active/dark_groups 与单采样同量级。 */
  for (i = 0; i < LINE_CHANNELS; i++)
  {
    if ((uint16_t)cnt[i] * 2u >= (uint16_t)LINE_OS_SAMPLES)
    {
      bm |= (uint16_t)(1u << i);
    }
  }
  return bm;
#else
  (void)cnt;
  return or_all;      /* 按位或：任一子采样亮就算亮 */
#endif
}
#endif /* LINE_OS_ENABLE */

void line_sensor_init(void)
{
  /* 引脚已在 CubeMX 的 gpio.c 配成 GPIO_MODE_INPUT, 这里无需额外动作。
     若改用 ADC 模拟量, 在此初始化 ADC。 */
  dwt_init();          /* ★给突发过采样准备微秒基准（LINE_OS_ENABLE=0 时也备着，无害） */
}

/* ============================================================================
 * ★★ 1kHz 红外采样（2026-09-23 晚）—— **只观测，不改变任何控制行为**
 *
 *  问题（用户实测观察）：葫芦圈出口那种图案**只持续一瞬间**，100Hz 的主循环
 *    （10ms 一拍，1m/s 时一拍走 ~10mm）会把整拍跳过 → 车"看不见"出口。
 *    他的原话证据：只有甩头时连续几拍压在那个图案上，才转出去过。
 *
 *  做法：**在 SysTick 里多采一次**（HAL 本来就是 1ms 一次 → 有效采样率 100Hz→1kHz）。
 *    ★为什么不把控制拍改成 5ms/200Hz：所有拍数常量都是按 10ms 定的
 *      （CROSS_REARM_FRAMES / GOURD_EXIT_TURN_FRAMES / LOST_MAX_CYCLES /
 *       STRAIGHT_BOOST_DELAY / 丢线拍数…），控制拍一改全要翻倍，漏一个就是一个坑。
 *      走 SysTick：控制拍和所有常量**一个都不用动**。
 *
 *  指标（遥测 K1= / MX=）：
 *    total  = 本窗口 1kHz 采样次数
 *    missed = 其中【与主循环最近一次读数不同】的次数 = "100Hz 漏掉的瞬间"数量
 *    maxraw = 本窗口里 active 最多的那个图案（一闪而过的宽图案在这里能看到）
 * ==========================================================================*/
#if LINE_SAMPLE_1KHZ
static volatile uint16_t os1k_total   = 0u;
static volatile uint16_t os1k_missed  = 0u;
static volatile uint16_t os1k_maxraw  = 0u;
static volatile uint8_t  os1k_maxact  = 0u;
static volatile uint16_t os1k_loopraw = 0xFFFFu;  /* 主循环最近一次读数（0xFFFF = 还没读过） */

/* SysTick 里每 1ms 调用一次。★必须极快：约 1µs（8 次位带读 + 几次比较） */
void line_sample_1khz(void)
{
  uint16_t bm  = line_raw_once();
  uint8_t  act = 0u;
  uint8_t  i;

  if (os1k_total < 60000u) os1k_total++;
  if ((bm != os1k_loopraw) && (os1k_missed < 60000u)) os1k_missed++;

  for (i = 0u; i < LINE_CHANNELS; i++)
  {
    if (bm & (uint16_t)(1u << i)) act++;
  }
  if (act > os1k_maxact) { os1k_maxact = act; os1k_maxraw = bm; }
}

/* 主循环每次读数后调用：告诉 1kHz 层"主循环这次看到的是什么" */
static void os1k_note_loop_raw(uint16_t bm) { os1k_loopraw = bm; }

/* 取本窗口统计并清零（返回值 = missed；其余走指针，可传 NULL） */
uint16_t line_1k_take(uint16_t* total, uint8_t* maxact, uint16_t* maxraw)
{
  uint16_t m, t, r;
  uint8_t  a;
  uint32_t pm = __get_PRIMASK();

  __disable_irq();                 /* 读+清要原子，否则可能丢掉 SysTick 刚记的一次 */
  m = os1k_missed; t = os1k_total; a = os1k_maxact; r = os1k_maxraw;
  os1k_missed = 0u; os1k_total = 0u; os1k_maxact = 0u; os1k_maxraw = 0u;
  if (!pm) __enable_irq();         /* ★恢复原状态：别把"本来关着中断"的调用者打开 */

  if (total)  *total  = t;
  if (maxact) *maxact = a;
  if (maxraw) *maxraw = r;
  return m;
}
#else
/* 关掉时给空实现，保证遥测那边不用改 */
void line_sample_1khz(void) { }
uint16_t line_1k_take(uint16_t* total, uint8_t* maxact, uint16_t* maxraw)
{
  if (total)  *total  = 0u;
  if (maxact) *maxact = 0u;
  if (maxraw) *maxraw = 0u;
  return 0u;
}
#endif /* LINE_SAMPLE_1KHZ */

line_reading_t line_read(void)
{
  line_reading_t r = {0, 0, 0};
  uint16_t bm;
  uint8_t  i;

#if LINE_OS_ENABLE
  bm = line_raw_burst();
#else
  bm = line_raw_once();
#endif

  /* ★error 与 raw 【必须同源】：都由最终位图算出来。
     这样任何"按位图做图案匹配"的判据（十字/出口/葫芦）都不会和 error 打架。
     （如果把 N 次 error 求平均，平均出来的方向可能对应一个不存在的图案。） */
  for (i = 0; i < LINE_CHANNELS; i++)
  {
    if (bm & (uint16_t)(1u << i))
    {
      r.error += kChannels[i].weight;
      r.active++;
    }
  }
  r.raw = bm;
#if LINE_SAMPLE_1KHZ
  os1k_note_loop_raw(bm);   /* ★把"主循环看到的结果"告诉 1kHz 层，用于统计漏看量 */
#endif
  return r;
}
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

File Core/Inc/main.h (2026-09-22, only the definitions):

#define LED1_Pin GPIO_PIN_13
#define LED1_GPIO_Port GPIOC
#define LINE_1_Pin GPIO_PIN_0
#define LINE_1_GPIO_Port GPIOA
#define LINE_2_Pin GPIO_PIN_1
#define LINE_2_GPIO_Port GPIOA
#define DIR1_Pin GPIO_PIN_4
#define DIR1_GPIO_Port GPIOA
#define DIR2_Pin GPIO_PIN_5
#define DIR2_GPIO_Port GPIOA
#define LINE_5_Pin GPIO_PIN_0
#define LINE_5_GPIO_Port GPIOB
#define LINE_6_Pin GPIO_PIN_1
#define LINE_6_GPIO_Port GPIOB
#define LINE_7_Pin GPIO_PIN_12
#define LINE_7_GPIO_Port GPIOB
#define LINE_8_Pin GPIO_PIN_13
#define LINE_8_GPIO_Port GPIOB
#define LED2_Pin GPIO_PIN_14
#define LED2_GPIO_Port GPIOB
#define LED3_Pin GPIO_PIN_15
#define LED3_GPIO_Port GPIOB
#define LINE_3_Pin GPIO_PIN_8
#define LINE_3_GPIO_Port GPIOA
#define LINE_4_Pin GPIO_PIN_15
#define LINE_4_GPIO_Port GPIOA
#define DIR3_Pin GPIO_PIN_3
#define DIR3_GPIO_Port GPIOB
#define DIR4_Pin GPIO_PIN_4
#define DIR4_GPIO_Port GPIOB
#define KEY_START_Pin GPIO_PIN_9
#define KEY_START_GPIO_Port GPIOB

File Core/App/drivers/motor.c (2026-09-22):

#include "motor.h"
#include "app_config.h"   /* ★必须有: MOTOR_LEFT_INVERT/MOTOR_RIGHT_INVERT 在这里 */
#include "main.h"
#include "tim.h"        /* htim2 */

/* ★守卫(2026-09-20 血泪): 少了上面的 app_config.h 时, #if MOTOR_LEFT_INVERT 会被当成 0
   → 反转静默失效(编译还不报错, 实测被这坑了一晚上)。留着它, 以后再犯直接编译报错。 */
#ifndef MOTOR_LEFT_INVERT
#error "motor.c 没包含 app_config.h: 电机方向反转宏会失效!"
#endif

/* 单侧电机驱动。逻辑从旧 change1/change2 迁移(含 2026-08-19 电机2方向对调的修复) */
void motor_set_speed(int vol, int16_t speed)
{
  if (speed >  MOTOR_SPEED_MAX) speed =  MOTOR_SPEED_MAX;
  if (speed < -MOTOR_SPEED_MAX) speed = -MOTOR_SPEED_MAX;

  /* ★方向映射开关（见 app_config.h 第四节）：正数 = 前进 */
#if MOTOR_LEFT_INVERT
  if (vol == MOTOR_LEFT)  speed = (int16_t)(-speed);
#endif
#if MOTOR_RIGHT_INVERT
  if (vol == MOTOR_RIGHT) speed = (int16_t)(-speed);
#endif

  if (vol == MOTOR_LEFT)           /* 电机1 = 左轮 */
  {
    if (speed > 0)
    {
      HAL_GPIO_WritePin(DIR1_GPIO_Port, DIR1_Pin, GPIO_PIN_RESET);
      HAL_GPIO_WritePin(DIR2_GPIO_Port, DIR2_Pin, GPIO_PIN_SET);
      __HAL_TIM_SET_COMPARE(&htim2, TIM_CHANNEL_3, speed);
    }
    else if (speed < 0)
    {
      HAL_GPIO_WritePin(DIR2_GPIO_Port, DIR2_Pin, GPIO_PIN_RESET);
      HAL_GPIO_WritePin(DIR1_GPIO_Port, DIR1_Pin, GPIO_PIN_SET);
      __HAL_TIM_SET_COMPARE(&htim2, TIM_CHANNEL_3, -speed);
    }
    else
    {
      HAL_GPIO_WritePin(DIR1_GPIO_Port, DIR1_Pin, GPIO_PIN_RESET);
      HAL_GPIO_WritePin(DIR2_GPIO_Port, DIR2_Pin, GPIO_PIN_RESET);
      __HAL_TIM_SET_COMPARE(&htim2, TIM_CHANNEL_3, 0);
    }
  }
  else                               /* 电机2 = 右轮 */
  {
    if (speed > 0)
    {
      HAL_GPIO_WritePin(DIR3_GPIO_Port, DIR3_Pin, GPIO_PIN_SET);   /* 实测反转, 电平对调 */
      HAL_GPIO_WritePin(DIR4_GPIO_Port, DIR4_Pin, GPIO_PIN_RESET);
      __HAL_TIM_SET_COMPARE(&htim2, TIM_CHANNEL_4, speed);
    }
    else if (speed < 0)
    {
      HAL_GPIO_WritePin(DIR4_GPIO_Port, DIR4_Pin, GPIO_PIN_SET);
      HAL_GPIO_WritePin(DIR3_GPIO_Port, DIR3_Pin, GPIO_PIN_RESET);
      __HAL_TIM_SET_COMPARE(&htim2, TIM_CHANNEL_4, -speed);
    }
    else
    {
      HAL_GPIO_WritePin(DIR3_GPIO_Port, DIR3_Pin, GPIO_PIN_RESET);
      HAL_GPIO_WritePin(DIR4_GPIO_Port, DIR4_Pin, GPIO_PIN_RESET);
      __HAL_TIM_SET_COMPARE(&htim2, TIM_CHANNEL_4, 0);
    }
  }
}

void motor_set_differential(int16_t left, int16_t right)
{
  motor_set_speed(MOTOR_LEFT,  left);
  motor_set_speed(MOTOR_RIGHT, right);
}

void motor_stop(void)
{
  motor_set_differential(0, 0);
}

void motor_init(void)
{
  HAL_TIM_PWM_Start(&htim2, TIM_CHANNEL_3);
  HAL_TIM_PWM_Start(&htim2, TIM_CHANNEL_4);
  motor_stop();
}

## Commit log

2026-09-22 初始提交：智能车循迹工程（新车 v2 装车 + 固件 FW:0922-0940）
    硬件：STM32F103C8T6 + TB6612 双电机差速 + 8 路灰度循迹 + JGA25 编码器 + 球脚轮三点底盘
    固件：分层框架(Core/App: drivers/control/fsm/telemetry)，状态机 IDLE→读秒→RUN→STOPPED/EMERGENCY
    本次功能：MPU6050(I2C2 手写驱动) / 直线提速到 99 / 葫芦弯相切点状态机 / 十字宽图案持续时间判据
    文档：文档/ + 机械结构/(3D 模型) + 硬件设计/(PCB+BOM)
    [BOM_Board1_Schematic2_2026-09-16.xlsx, 新底板-草案.dxf, 零件1.SLDPRT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]
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2026-09-22 修锁车问题(P0) + 若干健壮性改进 —— FW:0922-1330
    锁车根因（据《锁车问题-调研与修改建议-20260922》）：
    CAR_EMERGENCY 没有任何退出路径 → 一进就锁死，只能断电；最可能的触发是
    串口 RX(PA10) 悬空 + 电机 EMI 灌出假命令 X → 过弯电流大时最容易中招。
    改动（只按文档 P0 清单，未碰其'别动的东西'）：
    - car_fsm: 急停记录原因(按键/串口/其它) + 进急停时串口打印原因；
    新增解除路径 —— 急停里按住启动键 2 秒回 IDLE（不再只能断电）
    - key: 修'上电即长按'隐患（press_tick 初值 0 → 上电若按键已按下会误报长按）；
    开机头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
    [app_config.h, car_fsm.c, imu.c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]
2026-09-22 葫芦相切点判据按实测数据重写 + 翻转动作默认关闭 —— FW:0922-1500
    数据（他实跑截的 IR 位图）显示相切点的真实特征：
    00110011 -> 11000011 -> 00000011
    即「图案分裂成两组、往两边分离」，而不是我原先实现的「最外路亮(<=2路)再向内扩散」
    （旧判据在真实数据里根本不会触发：11100000 有 3 路亮 > 2）。
    十字是「一大片连着亮(>=5路)」、相切点是「两片分开」，两种元素天然分得开。
    改动：
    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
2026-09-22 fix: init 里的 gourd_flip/gourd_dir 也要放进 GOURD_USE_FLIP 开关（上一个提交编译不过）
    [line_follow.c]
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2026-09-22 新增：分支口（葫芦出口/直角入口）→ 硬转提交 —— FW:0922-1630
    数据（他实跑截的出口特征）：
    00110000(稳定循迹) -> 00111111(6路, 只贴右端) -> 车右转 -> 线滑到最左 11100000
    -> PD 看到巨大左误差又拽回来 -> 来回摆，吃不住那个 90 度出口
    根因：故意急转时传感器误差是误导的，必须"闭着眼把弯转完"再恢复循迹
    （国赛环岛的做法：用陀螺积分到 90 度再恢复；这里先用固定拍数实现，不依赖 IMU）
    判据（三种元素完全分开，互不冲突）：
    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
2026-09-22 回退 FW:0922-1630（分支口硬转提交）→ 回到 FW:0922-1500
    按用户要求回退上一版固件。b0aa0bf 新增的"分支口 → 硬转提交"整块撤掉：
    - 撤 USE_TURN_COMMIT / TURN_WIDE_MIN / TURN_COMMIT_FRAMES / TURN_COMMIT_PWM
    - 撤 line_follow.c 里的分支口检测 + 闭眼硬转提交逻辑
    - 撤 line_follow.h 的 line_follow_turn_commit()
    - 撤遥测的 TC= 字段
    - FW_TAG 回到 "0922-1500"
    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
2026-09-22 新增：弯道计数（最右一路 bit7 触发计数）→ 强制右转 —— FW:0922-1515
    他提的方案：不比特征，直接数"最右一路(bit7)"被触发几次，到阈值就强制右转 +
    串口打印"出葫芦弯道"。
    实现（Core/App/control/line_follow.c + app_config.h）：
    - USE_G7_COUNT：bit7 的【上升沿】计数 + G7_LOCKOUT(3 拍) 间隔
    ★关键：必须边沿计数，不能"每拍累加" —— 否则一次持续点亮会被算成几十次，
    而且绑死 10ms 拍/速度（test161 的老坑）。
    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
2026-09-22 修根因：葫芦出口被误当"十字"→ 强制直行 —— FW:0922-1531
    他诊断的根因（**对上了**）：葫芦弯出口被当成十字、按"直行"处理 → 直着冲出弯道。
    定位到具体那一行（Core/App/control/line_follow.c 宽图案判定）：
    旧判据 `r.active >= CROSS_ACTIVE_MIN(5)` → 只看"路数 ≥5"。
    而 `r.error` 是权重(-7..+7)求和 —— 用他实测的 IR 图案验算：
    真十字 11111111 → 路数 8 → e = 0 （对称，本来就该直行）
    葫芦出口 00111111 → 路数 6 → e = **+12** （只贴右端，本来就该猛右转）
    → 出口的 00111111 满足"路数≥5" → 被判成十字 → `e` 被强制清 0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
    [app_config.h, line_follow.c, telemetry.c]
2026-09-22 加"十字预算"层：按他给的赛道逻辑，第 5 次触发判为假十字 —— FW:0922-1542
    他给的赛道事实（我上一版缺的就是这个）：
    - **葫芦弯在两个十字【后面】**
    - **两个十字每个被触发 2 次** → 真十字共 4 次触发
    → **第 5 次触发一定是葫芦的假十字** → 从第 5 次起不当十字处理（交回 PD 转）
    这就把我上一版说的"顺序前提"补上了：实际触发次序是"真真真真 → 假假假…"，
    "次数"能对上"位置"。若葫芦夹在两个十字中间（真A 真A 假 假 真B 真B），预算会错位：
    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
2026-09-22 修：十字事件计数加防抖（一次过十字被数成 2 次 → 预算提前用完）—— FW:0922-1607
    实跑现象（他跑的 1542）：4 次过十字，**第 4 次就被判成假十字 → 车转弯**（本该直行）。
    本应第 5 次（葫芦）才拦。
    根因：**计数器在一次过十字里数出了 2 个事件。**
    计数按"宽图案的上升沿"，而 wide_cnt 只要有一帧 路数<5 就归零 →
    过十字当中图案抖掉一帧，就再冒出一个上升沿 → 同一个十字被数两次 →
    4 次过十字实际数到 5+ → 第 4 次真十字被预算拦下 → e 不再清 0，
    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
2026-09-23 文档：新增《给接手AI的复查提醒-20260923》+ 入口文档加必读指针
    - 确认 1b40238 已逐条落地 9/22 那份 P0 清单（急停原因/退出、key 上电误长按、PA10 上拉、X→XX、葫芦魔数、提速斜坡、IMU 超时 5ms）
    - 列出 3 个待处理风险：G7_TURN_TRIG 12 待实测标定；CROSS_BUDGET_MAX 4 是赛道硬编码，应改为实测 CX= 驱动；缺集中的决策优先级注释（已给出 1→9 顺序，可抄）
    - 未完成项：终点停车 / 速度闭环 / 蜂鸣器硬件 / 串口 RX 待实测确认
    - 文档索引与状态.md 顶部加指针，保证接手 AI 开场就读到
    未改动任何代码；未包含工作区那张微信截图
2026-09-23 12V 锂电池重标定：速度与增益 ×0.62 —— FW:0923-1917
    电池从 7.4V 换成 12V 锂电池（3S：标称 11.1V / 满电 12.6V）。TB6612 的 PWM 就是
    "占空比 × 电池电压"，所以同样的 PWM，电机平均电压变成 12/7.4 = 1.62 倍 → 车速 1.62 倍。
    旧标定（7.4V，实测）：60%→209rpm，99%→351rpm → RPM ≈ 3.59 × PWM，满速 ≈ 1.23 m/s
    新标定（12V）：RPM ≈ 5.8 × PWM，满 PWM ≈ 570rpm ≈ 2.0 m/s（★待实测确认）
    改了两样（都 ×7.4/12 = 0.617）：
    ① 速度值 —— 让"物理车速"不变：
    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
2026-09-23 导入队友版 0923-5400（QQ 传来的 git archive，源码基线 = 我们的 FW:0922-1607）
    来源：队友用 QQ 传的 `SMARTCAR-0923-5400.zip`（zip 注释里的提交 = 8cfcb329c8e7c9984d25943771aab12fb34c70aa，
    不在本仓库里）。他们的 git 账号还没注册、推不上来，所以只能这样交接。
    本分支**只为保存 + 可对比**，`main` 未改动。
    基线判定：他们的 `line_follow.c` 里有我们 9/22 最新的标记
    （`wide_armed`、`raw_rising`、"CROSS dup"、"GOURD EXIT (G7 count)"）
    → 确认是基于 `c028bca`（FW:0922-1607）往上做的；且"我们有、他们没有"的宏集合为空 = 超集。
    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
2026-09-23 文档：导入队友 9/23 实车复盘 5 篇（来自 QQ 传来的 0923-5400 包）
    队友的 git 账号还没注册、推不上来，所以这些复盘是 QQ 传的 zip 里带的。
    内容都是 9/23 一整天实车调出来的结论，含金量高，先搬进主线文档区保存：
    - `真相-3800为什么过不了葫芦圈-20260923.md`
    逐字节 diff + Code 体积 + 实车现象三证：3500/3800/4000 的 `USE_GOURD_EXIT` 一直是 0，
    **出圈逻辑压根没编进去**（"3500 能出圈"是错误记忆）。4100 开了图案判据后
    葫芦圈仍出不去、直角弯反而被误触发 → **图案判据彻底放弃**。
    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
2026-09-23 文档：跟进新基线（README 全面刷新 + 复盘文档补注 + 索引补指针）
    合并 0923-5400 后把文档同步到新基线，避免"代码是 5400、文档还停在 0922"的断层。
    README.md（原本停在 FW:0922-0940）：
    - 目录：补 `drivers/odom`、`Core/Src/freertos.c`、`Core/Inc/FreeRTOSConfig.h`、`Middlewares/`、`脚本/`
    - 串口命令表：补 `O`（读里程，手推标定用）/ `Z`（里程清零，不用断电反复测）；`X` 注明要连发两个
    - 遥测行：换成 5400 的真实字段，并逐字段解释（`DT`/`OD`/`PATH`/`ODE`/`OS`/`CX`/`BR`/`GE`/`GD`/`IG`/`EH` …）
    - 调参入口：按新分节重列，并加一句"app_config.h 已 780+ 行，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
2026-09-23 按实测修 KP（治甩头）+ 重标定 RPM_PER_PWM_X100 —— FW:0923-2100
    背景：12V 第一跑（FW:0923-5400）跑完全程、葫芦出弯也过了，但**全程甩头**。
    用串口做了【架空、空载】RPM↔PWM 扫描（每档 53 个样本）：
    PWM 30 40 50 60 70 80 99
    RPM1 153 211 267 324 379 434 535 (左)
    RPM2 156 216 275 334 391 450 556 (右)
    avg 155 213 271 329 385 442 545
    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
2026-09-23 打开速度闭环（用户要求"速度闭环你先测试"）—— FW:0923-2120
    改动只有一行：`USE_SPEED_LOOP 0 → 1`（app_config.h）。
    为什么是这个顺序（先闭环、再大胆提速）：
    开环下同样的 SP 在满电/半电跑出来的车速不一样（实测 k 与电池电压成正比：
    他测 5.7 / 我测 5.42，差的就是电量）。闭环把这个漂移消掉 →
    **"SP 值对应的车速"才变得可预测** → 提速才敢一次跨大步。
    开闭环前的三项检查（都过了才动）：
    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
2026-09-23 新增 SysTick 1kHz 红外采样（只观测）+ 打开速度闭环 —— FW:0923-2126
    用户要求两件：① "在 SysTick 里加一次红外采样，就这个，干吧" ② "先速度闭环，提速排到最后"。
    一、速度闭环：`USE_SPEED_LOOP 0 → 1`（见上一个提交 c6e4f93 的说明）。
    开之前核过：pid_init 用 SPD_PID_KP/KI/KD(0.4/0.1/0) 不是 0 增益、bias=0、目标换算正确。
    二、**1kHz 红外采样**（Core/App/drivers/line_sensor.c + Core/Src/stm32f1xx_it.c + telemetry.c）
    要解决的问题（用户实测观察）：**葫芦圈出口那种图案只持续一瞬间**，100Hz 主循环
    （1ms 走 1mm，1m/s 时一拍 10mm）会整拍跳过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
    [app_config.h, line_sensor.c, telemetry.c]
2026-09-23 修闭环的一个致命细节：测速从遥测拍挪到控制拍 —— FW:0923-2129
    问题（今晚验证闭环时发现）：`speed_update()` **全工程只在 `telemetry_report()` 里被调用**
    （唯一的周期调用点）。而控制走的是 `car_fsm_run()` → `line_follow_control()` →
    `speed_get_rpm()`。所以：
    闭环每 10ms 跑一次，但读到的转速是【50ms 前的旧值】→ 连续 5 拍用同一个 RPM。
    实测症状（架空闭环验证）：
    M 30 → 目标165 实际157/160 M 40 → 目标220 实际206/210
    M 52 → 目标286 实际277/285 M 70 → 目标385 实际370/382
    → 能稳在附近，但稳态差 2~7%、修正慢 ——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
    [app.c, app_config.h, telemetry.c]
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2026-09-24 关掉"直线提速"—— 查实它就是"猛冲 + 蛇形弯乱冲"的元凶 —— FW:0924-1804
    他反馈："猛冲问题没改，好像是我之前写的一个直道加速搞的鬼，现在再看这个是怎么回事，
    现在总是在蛇形弯道乱冲导致失线"。
    读代码后确认他的怀疑成立，机制如下：
    判"直"的唯一依据是 `(r.active>0) && |e|<=STRAIGHT_BOOST_ERR_MAX(1) && !on_cross
    && !wide_long && !line_lost` 连续 STRAIGHT_BOOST_DELAY(100 拍 = 1 秒)
    → **蛇形弯的中段本来就经常穿过中心线**，误差在 ±1 里待够 1 秒太容易 → 它在蛇形弯里提速；
    一升，|e| 立刻 >1 → `straight_cycles=0; boost_active=0`（释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
    [app_config.h, line_follow.c]
2026-09-24 里程转头关掉(改用抓形状) + 修 GYRO_CONFIG 档位量纲 bug (GZ 放大 8 倍) —— FW:0924-1857
    [app_config.h, imu.c]
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2026-09-24 修正 FW_TAG 为 0924-1948（上一次 sed 没匹配上）
    [app_config.h]
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2026-09-24 让出圈判据可验证：把 GW=/IG= 加进默认短行遥测 —— FW:0924-2145
    ## 问题
    默认短行是
    FW:%s ST=%d IR:%s RPM1=%d RPM2=%d OD=%ld GZ=%d K1=%d
    里面【没有 GW，也没有 IG】；带 GW/IG 的完整长行要靠发 `H` 命令取。
    而本车【PC→车 RX 不通】(见 文档/给队友的交接-20260924晚.md 与 88c5e44)，
    发不了命令 -> 交接文档第三节第 4 步的验收
    "葫芦里 GW 应 1->2->0、直角弯必须一直是 0"
    根本无从检查。
    ## 改动
    telemetry.c 默认短行加 GW= 与 IG=：
    ... OD=%ld GZ=%d GW=%d IG=%d K1=%d
    行长 ~67 -> ~78 字符，仍在 80 列内。buf[96] -> buf[112]。
    GW = 相切点计数(0..GOURD_TOTAL)：葫芦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
    [app_config.h, telemetry.c]
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2026-09-24 摆幅收住了：KD 1.0 -> 1.1（稍微加阻尼）—— FW:0924-2405
    用户实测反馈："好多了，现在只有轻微的左右摆动，也不怎么影响循迹，
    稍微增大一点 kd 就行。现在的问题就是过不了葫芦圈"
    KD 1.0f -> 1.1f
    KP 保持 2.5f
    => D/P 比值 1.1/2.5 = 0.44（原设计 0.40），略微偏阻尼 —— 正是"再压一点摆幅"要的。
    ## 为什么只加 0.1
    本行下面那条警告是实测踩过的："给多了会抖（IR 单拍闪烁会被 D 放大）"——
    上次 1.2 就是抖的来源之一。所以按用户说的"稍微"处理，一次只挪一小步。
    调参方向：还轻微摆 -> 1.2；开始出现高频"抖"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
    [app_config.h]
2026-09-24 治"绕圈"的正解：打开相切点翻转修正 GOURD_USE_FLIP 0 -> 1 —— FW:0924-2450
    ## 病根（用户一句话定位）
    用户："绕着第 1 个葫芦圈转了两圈差不多"
    => 车进了葫芦圈就【锁在第 1 个圆上绕圈】，根本没走到出口。
    所以之前一直在调的"出圈判据"根本不是问题 —— 车压根到不了出口。
    也解释了用户为什么"在猛地右转前就把小车拿走"：
    里程是在【绕圈时】才凑够 24847 的，那时候触发点早就没意义了。
    ## 机理
    葫芦圈 = 4 个外切圆，走线是蛇行 S 波。
    相切点处走线要从圆 1 跨到圆 2，而【圆 2 的曲率方向与圆 1 相反】——
    车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
    [app_config.h, line_follow.c]
2026-09-24 相切点识别改用 1kHz 过采样位图（用户方案：提高识别采样率）—— FW:0924-2520
    ## 用户的实测观察（本轮的关键）
    "我发现小车在过这个葫芦圈里的弯道的时候转速特别大，实际上的识别窗口就变小了。
    你看一下能不能增大采样率，如果提高这个都不行的话就是这识别到葫芦圈就降一下转速"
    完全正确：车转得快 -> "宽 + 只贴一端"那个图案可能只存在 1~3ms，
    而相切点判据原来只看 100Hz 那一拍（每 10ms 采一次）-> 直接漏掉
    -> 相切点识别不到 -> 翻转修正不触发 -> 车锁在同一个圆上绕圈。
    ## 关键发现：数据早就在手上，只是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
    [app_config.h, line_follow.c, telemetry.c]
2026-09-24 修复"识别到相切点却不往外拐"：翻转修正原来只写在两个进不去的分支里 —— FW:0924-2545
    ## 实车现象（用户）
    "发现小车很明显的抓到了那个窗口，问题是不往外拐，仍然在一直绕圈"
    => 识别成功、动作没生效。这直接把范围缩到"gourd_flip 有没有真的作用到 e 上"。
    ## 病根：死代码
    翻转覆盖原来只写在两个分支里：
    ① line_follow.c:1176 if (r.active == 0) 短暂【丢线】
    ② line_follow.c:1224 else if (wide_long) 宽图案【持续过久】
    而相切点的实际情况是：
    · 线一直都在 —— 队友判据③原话："事件后 6 拍内【不出现全灭】…相切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
    [app_config.h, line_follow.c]
2026-09-24 回退"正常路径翻转覆盖"：实车无效果且摆头加重 —— FW:0924-2600
    ## 实车结果（用户）
    "没有效果。而且头左右晃的更厉害了"
    ## 为什么回退
    翻转触发门是 `if (ge_in_gourd && ...)`，而 ge_in_gourd(IG) 本身会误触发
    （GOURD_IG_SUM_TH=1000 是陀螺量纲修好【之前】定的）。
    · 以前误触发只让 GW 计错一下（无害）；
    · 把覆盖接到正常路径后，每次误触发都 = 给车 15 拍【错误的反向修正】→ 摆头明显加重。
    · 而葫芦圈毫无变化 → 说明它在【真正的相切点】反而没触发。
    两头都不对 = 触发时机本身不可靠。在这个前提下继续加码只会越修越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
    [app_config.h, line_follow.c]
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2026-09-24 关掉出圈右转 + 治"绕圈"：宽图案持续时改成【走直线】 —— FW:0924-2740
    用户要求："你先把葫芦圈的问题解决了，可以先把右转关了，后面再单独解决"
    ## 一、关掉出圈右转（按要求）
    四个出圈触发全 0：
    GOURD_EXIT_USE_GW 1 -> 0
    USE_GOURD_EXIT_ODOM 1 -> 0
    GOURD_EXIT_USE_PATTERN 0（本来就 0）
    GOURD_EXIT_ON_LOST 0（本来就 0）
    GOURD_USE_FLIP 1 -> 0（顺带，翻转也一起收起来）
    => trig_now 恒为 0 => ge_turning 永不置位 => 右转【结构上不可能发生】。
    ★为什么保留 USE_GOURD_EXIT=1 而不是改 0：
    改 0 会让 gourd_wrap_evt 变成"只写不读"-> ARMCC #550-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
    [app_config.h, line_follow.c]
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2026-09-26 葫芦圈：陀螺量程改 ±2000dps（治削顶）+ 打开 GOURD_ARC_FLIP 偏航积分换向
    ## 背景：葫芦圈问题已失败三次，且都是同一类做法
    ① 相切点直行窗口 (9-24) ✗ 更差（第 1 个圈就绕圈）
    ② GW 计数触发出圈 (9-24) ✗ 走不了葫芦圈
    ③ 直行窗口 + 宽度上限 (今天) ✗ 触发 13→20 次、绕圈更多（已回退）
    根本原因（文档/相切点为什么IR识别不了-几何结论-20260924.md 第 3 节，有日志实证）：
    两个【外切】圆在相切点【共用一条切线】→ 走线 C¹ 连续、线不变宽也不分叉
    ⇒ 相切点在 IR 上【不可见】（实测绕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
    [imu.c]
2026-09-26 Revert " 葫芦圈：陀螺量程改 ±2000dps（治削顶）+ 打开 GOURD_ARC_FLIP 偏航积分换向"
    This reverts commit b34b8c6bb96edee06b4080f26170a8db00d95eaf.
    [imu.c]
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2026-09-26 陀螺削顶：先加观测（SAT=/SATN=），不再盲改档位
    ## 调查结论：±2000dps 档在这颗芯片上不可用，且【改代码修不了】
    证据链：
    09-24 写 0x18(±2000) → 写不进去，芯片留在 ±250 默认档 → GZ 读数大 8 倍（imu.c 顶部注释）
    09-24 改 0x10(±1000) + 读回校验 → 生效，GZ 正常
    今天 再写 0x18 → GZ 恒为 0（比写不进去更糟），已 revert
    0x10 与 0x18 只差 FS_SEL 一个 bit（2 vs 3）：
    前者稳定可用，后者直接坏 ⇒ 这颗芯片（大概率国产 MPU6050 克隆）
    的 FS_SEL=3 位是坏的/未实现的 —— **不是配置错误，改代码解决不了**。
    ⇒ ±1000dps 已是它能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
    [app_config.h, imu.c, telemetry.c]
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2026-09-26 参考 balance.c 的角度解算对比：pitch/roll 互补滤波改用实测 dt
    ## 对比结论：yaw 没问题，无需换四元数
    参考实现（balance.c）是【六轴四元数姿态解算】（Madgwick/Mahony 风格，带 PI 修正 + 归一化）。
    逐个对比后确认：
    · **yaw 两边本质相同**：参考里 `ez`（绕重力轴的误差）根本不参与 yaw
    （源码注释"ez 不使用"、"z 不修正"），最后 yaw 也是从四元数推出来的【纯陀螺积分】。
    原因一样：**重力给不出"绕重力轴转了多少"的信息**，加速度计在物理上测不到 yaw。
    ⇒ 本工程【不做 yaw 的加速度计修正】是【正确】的，不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
    [imu.c]
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2026-09-26 葫芦圈后半段减速：打开 USE_GOURD_SLOWDOWN（并修掉让减速失效的清零逻辑）
    ## 为什么试这个
    葫芦圈仍要绕约 3 轮（基线 FW:0926-1900：圈内 10872mm，真正只需 1.8~2m）。
    几何原因（app_config.h 里原有的长注释，非本次新发现）：
    外切点 = 两个圆的【曲率突变点】（小圆→大圆，所需转向半径突然变大）。
    PD 靠 error 反应、会慢一拍 → 在衔接处"切内角" → 车身斜着出切点 →
    正好从两圆之间的缝隙穿过去（那里没有线）→ 传感器全灭 → 丢线。
    减速对症：速度低 → 每拍位移小 → 同样的 error 变化率下修正更充分
    →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
    [app_config.h, line_follow.c]
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2026-09-29 FW:0929-R1 修复葫芦圈转向记忆、丢线恢复及编码器回绕
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2026-10-08 FW:1008-R5 纯观测版：默认短行把 AR/AN 换成 C(corr) / P(实际 PWM) / S(速度基准)
    为什么（不改任何控制行为，只改打印）：
    ① AR/AN 在 GOURD_ARC_FLIP=0 下恒为 0（作者原注释"恒为 0 = 机制从未跑起来"），
    白占位置；
    ② 现在排查"直行残余抖动 + 右轮测速可疑"缺的正是这三个量：
    C = 本拍差速修正 corr（±99 夹过）→ 摆多大、什么相位
    P = 本拍真正下发的左右轮 PWM → 与 RPM 对照就能分岔：
    左 33 / 右 58 而 RPM 右 = 0/14 ⇒ 右轮速度环被假反馈顶到饱和
    左 ≈ 右 而 RPM 右 = 0/14 ⇒ 右轮电机/机械确实慢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
2026-10-08 FW:1008-R7 修正"测速断线"保护的判据（R6 那版在实车上从未触发）
    R6 用的是"连续 20 拍同时满足"，实车（FW:1008-R6 日志）一次都没触发，原因在数据里：
    · 判据① |m2|>=18 —— 但转向会把 m2 抢小：C=17、S=24 时 m2 = 7 < 18 ⇒ 卡死；
    · 判据③ 要求"另一轮连续 20 拍 >=60" —— 车一乱甩左轮就掉到 16~38 ⇒ 永远连不上 20 拍。
    修正：
    · ① 门槛降到 8（= WHEEL_FLOOR_MIN_CMD，"没在驱动"的同一道线）；
    · ③ 改成【锁存】：任一测速 >= 40 就给 s_fb_move 续期 0.5s，不再要求连续；
    · 计数改成【漏桶】：满足 +1、不满足 −1（不清零），cor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
2026-10-08 FW:1008-R8 分支口触发加两道防抖（治"有时过有时不过"）
    问题（用户实测）：葫芦圈"有时候能过，有时候不能过"，怀疑转圈时转向太猛导致切入方向判错。
    先修第一条机制 —— 也是我 1008-R2 自己埋的雷：
    BRANCH-EDGE 的"左右交替"是【计数式、无反馈】的：多触发一次或少触发一次，
    后面每个相切点的分支都会反过来 ⇒ 表现就是"有时能过有时不能过"。
    本项目对同类问题早有结论（文档原文）："误报是成簇的：一次真实宽图案被判成
    2~3 个相切点"，并为此给"相切点计数"加了 GOURD_WAVE_MIN_MM=200mm ——
    而 BRANCH-EDGE 当时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
2026-10-08 FW:1008-R9 从 G88 移植【不许把轮子停住/反转】（治弯道左右晃）
    用户实测：直线好了；"左右晃又回来了，主要在弯道"；葫芦圈不再误判（R8 的防抖生效）。
    而 G88 那条线的 FW_TAG 注释写的正是这个病：内轮被速度环压停 → 车绕着它打转 → 起不来。
    机制（G88 的记录，两趟实车日志左右镜像完全对上）：
    ① 大修正 → 内轮"本意" ≤ 0 → 输出把它刹住/反转；
    ② 内轮停下 → 只能靠外轮推 → 车开始绕着这个停住的轮子打转；
    ③ 要它重新滚起来得克服接触点静摩擦 ≈ μNr ≈ 0.17 N·m（与堵转力矩同量级）→ 起不来；
    ④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
2026-10-08 FW:1008-R10 修正 R9 的 NO_STOP_BRAKE：改成"跟着本意走"（R9 把葫芦圈治坏了）
    实车（用户）：R9 之后"弯道没问题了，但葫芦圈过不了"。
    机制（算一下就知道）：R9 照搬了 G88 最狠的写法 —— 连【本意倒转】的轮子也抬成 +18。
    但"本意倒转"正是【刻意原地转向】的正常手段（BRANCH-EDGE 分支口 / 大修正急转都靠它）。
    G88 的作者当时没有 BRANCH-EDGE 这个模式，所以他写的"不受影响：出圈右转 / 丢线旋转
    都在别的路径上"在我们这儿不成立。
    算例：sp=24、corr=±30（分支口那一下）→ 本意 m1 = 24−30 = −6
    → R9 把它抬成 +18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
2026-10-08 FW:1008-R11 = R10 的本意修正 + 黑匣子改成"只在行驶中记录"
    一、R10 的修正（本版一并带上；上一次烧录时车是关着的，R10 没进板子）
    R9 的 NO_STOP_BRAKE 连【本意倒转】的轮子也抬成 +18 ⇒ 把"刻意原地转向"也禁掉了
    ⇒ 实车表现：弯道好了、葫芦圈过不了（分支口那一下差速从 60 掉到 36，少 40%）。
    R10/R11 改成跟着本意走：
    本意 > 0 → 至少 +MIN_ROLL；本意 < 0 → 至多 −MIN_ROLL；本意 = 0 → 不动。
    二、黑匣子记录条件（本版新增；纯记录，不碰任何控制）
    原条件 `if (!line_follow_in_gourd()) return;` 依赖 IG，而 IG 依赖陀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
2026-10-08 FW:1008-R17 【倒转限时】治"卡在第 2 个圈"（允许猛转，不许长期倒转）
    用户实测更正（R16 那趟）：**不是出圈的问题** —— 是葫芦圈现在过不了，一直卡在第 2 个圈。
    黑匣子给出的"卡死"稳态（就是卡住那一刻的原始画面）：
    PWM = -18/54 IR = 01100000(线在左起第 2、3 路) e = -8 cor = -30 sp = 24
    ⇒ 左轮（内轮）被命令【倒转】→ 车绕着被刹住的内轮原地打转，
    线一直停在同一个位置、怎么转都回不到中心 ⇒ 死锁（净里程不再增长，黑匣子在此冻结）。
    为什么 cor 会到 -30（= 内轮为什么会倒转）：
    e=-8、滤波后 e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
2026-10-08 FW:1008-R22 出圈判据⑤：里程窗口 + T 形图案（本版先跑标定；减速本轮不启用）
    【几何修正（用户拍照确认）】葫芦圈出口是一个 **T 形三岔**：
    一条笔直的出口线【垂直】落在圈线（圆弧）上，交点就在圆弧最高点，圆弧左右都继续延伸
    ⇒ **线不会消失，车顺着圆弧当然能接着走** —— 这才是它一直绕圈的真正原因。
    ⇒ 旧判据②"圈内持续丢线 = 出口"对不上这个几何。
    R18 那趟我看到的 IR 全灭是"跑完之后丢线原地转"，不是 T 形口
    —— 那次判断我做错了，已把结论写进配置注释以免重犯。
    【新增判据⑤】两个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
2026-10-08 FW:1008-R24 分支口触发的 RAM 台账（+ 重要更正：葫芦圈需要翻转 7 次，不是 3 次）
    【用户提供的关键事实】葫芦圈跑完需要【翻转 7 次】（不是我一直假设的 3 次）。
    ⇒ 这把我之前的诊断整个翻过来了：
    · 我一直把"BRANCH-EDGE 触发 6 次"当成"多了 3 次误触发"⇒ 去压触发（加门、加防抖）；
    · 真相是【少了】：需要 7 次，只触发 6 次 ⇒ **漏掉了某个切点** ⇒
    从漏掉那一次起，"左右交替"的相位就错了 ⇒ 后面的圆全部选错边
    ⇒ 表现就是"卡在第 N 个圈"（用户这趟是第三个圈）。
    ⇒ 修正方向也随之反转：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
2026-10-08 FW:1008-R25 关掉出圈判据②（它会误判出圈、并把整套葫芦圈逻辑关掉）
    R24 那趟（用户："这一次没问题"）读芯片发现：
    分支口台账 3 条，结构都干净（act=5、nb=1~2）：
    #1 OD 11049 L (nb=2) #2 OD 11612 R (nb=2, +563mm) #3 OD 12028 L (nb=1, +416mm)
    但 【出圈】GE=1、ge_fired=1、armed=0 ← 出圈转向又触发了！
    判据⑤在标定模式下是【编译掉】的 ⇒ 只可能是判据②（"圈内持续丢线"）干的。
    ⇒ 判据②在 R18 就已被证明与 T 形出口几何不符（出口线不会消失、车能接着走），
    而我把它一直留着 ⇒ 圈内任何一次持续丢线都会误判出圈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
2026-10-09 FW_TAG 修正：R27 之后我漏改了（板上 R29/R30/R31 都还报 1008-R27）⇒ 现在改为 1008-R32
2026-10-09 FW:1008-R34 修 R30 的相位 bug：两坨状态改成每拍更新（台账实测 L,R,R,R = 第3个切点起不再翻转）
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2026-10-15 R72c: 删掉误插入到旧位置（R63那处）的重复 R72 块（锚点文本有两处，Replace 全替换了）
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2026-10-15 R83b: 修正 FW_TAG（自R73重置后被还原成R74，R75~R82的替换都没匹配上，一直误报）⇒ 现为 1008-R83
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2026-10-15 R110: 修正——终点里程恢复安全占位14000 + 加(EXIT_FINISH_MM>0)保护（上版误把乱码0写入，会让任何异常都停车）
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2026-10-16 直道提速：补"迟滞 + 释放冷却"（用户 9-24 笔记预登记的 ②③，只动这一个变量）
    - 病根：R121 只做了"150拍/40/+2斜坡"，退出仍是 |e|>2 立即回落 → 阈值附近来回穿 = "冲-慢-冲"打摆
    - 改法（进严出宽 + 冷却）：
    进 |e| <= STRAIGHT_BOOST_ERR_MAX(2) 连续 150 拍（不动，用户选的数）
    出 |e| > STRAIGHT_BOOST_EXIT_ERR(4) 才退（新宏，迟滞带 3）
    出后冷却 STRAIGHT_BOOST_COOLDOWN(50拍=0.5s) 不许重新进入（新宏）
    - 回退：EXIT_ERR 改 2 且 COOLDOWN 改 0 = 完全回到 R121 行为；或 git reset --hard anchor-1016-r122
    - 声明/复位/使用同进同出（boost_cool 收在 #if USE_STRAIGHT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
2026-10-16 遥测加 TIM: 字段（用户要求，纯打印零行为变化）
    - 短行/长行都在 FW 之后插入 TIM:<ms>（HAL_GetTick 轮询时钟，非硬件定时器）
    - 用途：串口观察的时间轴——发车行当 t0，后行减它 = 相对发车多久
    - 位置靠前：防行尾被吃（项目教训"诊断量往前放"）；行长 ~87 字符（原 ~75，仍在 ≤95 内）
    - 编译 0 Error 0 Warning；逻辑地图 §6 同步
    - 提速门槛（ERR_MAX/DELAY）按用户要求未动：等观察后再定值
2026-10-16 docs: 接手文档补"本机验证过的烧录/读串口命令"（OpenOCD + readdap.ps1）
    - 2026-10-16 实测：Keil UV4 -f 不产出 flash.log（不确定是否真烧）；OpenOCD CMSIS-DAP 一次成功
    （Programming Finished / Verified OK / Resetting Target）
    - 烧录后串口确认新固件在跑：tag 1008-R122 + 每行 TIM: 字段生效（500ms 待机节奏）
    - 新增脚本 _tmp/readdap.ps1（自动找 CMSIS-DAP 的 CDC 串口）
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2026-10-16 文档：§6.15 圈内逻辑=两个独立计数器（GW/BRANCH-EDGE）+ 概率问题机理假设（相位只在'两坨'那拍翻，漏翻则后面全反）+ 三个候选修法（先走零改动诊断）
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2026-10-16 1016-R153/R154：切点3 也上"只许左" + 触发状态改"3 灯流水灯"（删闪灯）+ 槽③ 回 16400
    R153（他："继续调第三个切点，窗口期中间我们开LED闪灯"）：
    - GSP_ONEWAY_MASK 0x02→0x06（切点2 只许右 + 切点3 只许左）
    - GSP_BLINK_MASK 0x02→0x06（切点2/3 窗口都闪）
    R154（他："之前的切点2的窗口的LED闪灯也删掉防止我误判；出口出问题是说变晚了，
    这个可以用3个LED流水灯表示触发状态"）：
    - GSP_BLINK_MASK → 0（闪灯整套停用）
    - 新 GSP_LED_MASK 0x07 + GSP_EXIT_LED 1：哪个切点【方向窗口】开着就点哪个 LED（过葫芦时 1→2→3
    流水灯）；出口右转那 2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
2026-10-16 文档：R160 已烧上（DAP 卡死自愈）+ 记一条排错经验
    - 现场记录 §6.50：烧录先报 CMSIS-DAP command CMD_INFO failed（100/50kHz 都试），
    隔几分钟原样重试 ⇒ Programming Finished / Verified OK。
    ★经验：这个 DAP 卡死有时会自己缓过来，先别急着拆线；仍不行再拔插 USB。
    ★另注：烧成功时他的 fireTools 仍占着 COM17 ⇒ "串口被占"与"DAP 卡死"是两件独立的事。
    - 接手文档/索引：车上固件 = FW:1016-R160（banner 因串口被占未读回）。
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2026-10-16 1016-R162：★查出"出口又没触发"的真因（出口锁从没复位）+ 出口触发=三灯闪 + 切点3 停闪
    他的两句（原话）："怎么出口又没触发了呀，你改了啥" /
    "出口触发阶段现在LED3灯闪烁，然后切点3窗口期不要闪灯了，以免误判"
    先回答"改了啥"（有据）：从他验收过的 R154(b5d7fd8) 到现在，出口那条链一个字没改 ——
    git diff -w 里 EXIT_*/GOURD_EXIT_* 全为空。改过的只有三处且都在出口之外：起步三件套（R160 已回退）、
    最后直角弯窗口（在出口之后 3.4m）、LED 指示（纯显示）。
    真因（老 bug，不是这次改出来的）：s_ex_done（出口"一趟只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
2026-10-16 文档 §6.54：核实"读秒没被算进里程"（不是它的锅）；"起步直行没生效"的真因 = R160 已关 + 开着也肉眼不可见； 顺手查出 s_corr_trim（转向微调，±25 PWM）不是每趟清零（line_follow_stop 是死代码）—— 未改，等他定
    他的原话："我发现一个问题，你说开跑先直行，但是我看的实际上一直没有实现，我现在想明白了，
    我开始会有3秒报数，你是不是算在这里面了，"
    ① 假设不成立：CAR_COUNTDOWN 期间每拍 motor_stop()（不产生脉冲），数满那一刻先 odom_reset()
    下一行才 enter(CAR_RUN)；odom_init() 以清零那一刻的编码器读数为基准 ⇒ 起步第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
2026-10-17 文档：R168 已烧上（他给车重新上电后一次烧过）+ 记"车不上电就烧不进"这条排错实锤
    - §6.59 标题改为"已实施 + 已烧录"；烧录经过如实记录：先 DAPLink 不在 USB ⇒ 他重插 ⇒
    连续 6 次 CMD_INFO/CMD_DAP_SWJ_CLOCK failed（100/50kHz、无残留进程、设备状态全 OK）⇒
    他给车重新上电 ⇒ 一次烧过（device id 0x20030410 / Verified OK）。
    ★实锤：车不上电就烧不进（下次先上电再怀疑线）。
    - 串口确认 tag : 1016-R168（built Oct 17 2026 08:30:49）在跑。
2026-10-17 1016-R169：盲走段 800 → 150mm（"偏左、没直行"是同一件事：闭眼走直必然偏）
    他的反馈（原话）："盲走太长而且，方向不对，偏左，没有直行"
    为什么"闭眼走直"会偏左（算得出来的）：
    - 闭眼走直 = 两轮给同样目标；而本车两轮同 PWM 差 2~4%（右编码器 R=0 ⇒ 右轮被
    SPD_DEAD_FB_GUARD 判"测速断线"退回开环；历史空载扫描也实测右轮略快）；
    - 偏航 ≈ (Δv/v)×(盲走里程/轴距)：800mm ⇒ ~18° 偏航、约 12cm 横移（就是"明显往左弯"）；
    150mm ⇒ ~3°、约 4mm（可忽略）。
    ⇒ 盲走越短，"走不直"越不成问题，不必配补偿。
    改动：START_STR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
2026-10-17 1016-R171：只改一个参数 —— WHEEL_GAIN_L 1.00 → 1.05（左偏就加左轮速度）
    他的指令（原话）："还是左偏，不要随便改东西，改参数就改参数，左偏就加左轮速度"
    ★协作规矩（记档）：参数问题就用参数解决；追参数时不要顺手改逻辑/加新机制。
    改动：WHEEL_GAIN_L 1.00f → 1.05f（速度环最终输出那一级 m1 = o1 × WHEEL_GAIN_L）
    ⇒ 左轮最终 PWM ×1.05 ⇒ 左轮更有力 ⇒ 车往右修 ⇒ 抵消左偏。
    取值依据：历史 1.11 时车"恒定向右偏"、1.00 时偏左 ⇒ 正确值在中间，先取 1.05；
    还偏左 ⇒ 1.08/1.10；变偏右 ⇒ 1.02/1.03。
    ★顺带发现：只改常量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
2026-10-17 文档：R171 已烧上（DAP 卡死 → 第 3 次重试自愈）
    - 现场记录 §6.62 标题改"已实施 + 已烧录"；烧录经过：先连续 5 次 CMD_INFO failed
    （他给车上电后仍失败）⇒ 隔几秒原样重试第 3 次就过，随后 100/50kHz 都能烧（device id 0x20030410 / Verified OK）。
    ★经验补充：这个 DAP 的失败多数"重试就好"，别急着拆线。
    - 接手文档/索引：车上固件 = FW:1016-R171（banner 因串口被占未读回）。
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2026-10-17 规矩：以后烧录由他本人做（他："你以后不用代替我烧录了，太慢"）
    分工变更：
    - 我只负责：改代码/参数 → build.ps1 到 0E0W → 给出 hex 路径（MDK-ARM/test16/test16.hex）+ FW_TAG
    - 烧录 + 串口验证由他做
    原因：我这边 OpenOCD 反复 CMD_INFO failed / 设备枚举掉线，他的串口工具又常年占 COM17 ⇒ 重试太慢。
    不变：0E0W 才给 hex；FW_TAG 一版一签。
    同时记档：R175/R176 = 起步窗口 0~500mm（900→500）、LAUNCH_SPD 36→40→35（他"改成35"）；
    R176 已由我最后一次烧上（Verified OK），此后不再代烧。
    更新：现场记录 §6.67、接手文档工作方式、项目记忆 +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
2026-10-17 1016-R177：开"切点1 窗口 ⇒ 三灯闪"（GSP_BLINK_MASK 0x01）
    他的指令（原话）："这个第一个切点又出现问题了，现在开第一个切点的窗口期持续LED闪烁"
    改动：GSP_BLINK_MASK 0x00 → 0x01（bit0 = 切点1）⇒ 切点1 窗口期内三灯同时闪
    （节奏 GSP_BLINK_MS 50ms ≈10Hz）；切点3 仍不闪（R162 定的：它离出口只 82mm，两处都"三灯闪"会误判）。
    闪的区间（方向窗口）：绝对 OD ≈ 11479 ~ 11839（中心 = 锚 11176 + 633 − BIAS 150，半宽 180）。
    判读：真切点偏"闪的前半段" ⇒ 窗口早了 ⇒ GSP_BIAS_MM 加大；偏后半段 ⇒ 减小（一次只动这一个数）。
    0E0W（Code=317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
2026-10-17 文档 §6.70：烧录排错 —— 他换 ST-Link，SWD 链路不稳（探测 1/3 成功、12 次烧录全失败；目标电压 3.095V 偏低）
    - 报错地址五花八门（DEMCR/DWT/FLASH 解锁/flash 容量）⇒ 不是 hex/固件问题，是 SWD 链路本身不稳；
    - 试过 1000/100/20/5kHz 全失败；connect_assert_srst 也不行；
    - 目标电压 3.095V（偏低）；ST-Link 型号 V2J46S7（不是以前那台 V2J37S7）；
    - 建议：换回 DAPLink（今天成功十几次）/ Keil F8 / 重插 4 根杜邦线（GND 尤其）/ 换满电电池。
    - R178 hex 已就绪（0E0W），未烧上（车上 R176）。
2026-10-19 文档：R178 已烧上（换回 DAPLink，探测一次即通 → Verified OK；串口确认 tag : 1016-R178 built 11:49:50）
    - §6.70 标题/结局更新：他换 ST-Link 失败（SWD 链路 1/3 通、4 档速度都不行、目标电压 3.095V 偏低）；
    弄好 DAPLink 后一次探测即 Examination succeed、当次烧录 Verified OK。
    - 车上 = R178（切点1 窗口 683 = OD≈11529~11889；切点1 三灯闪 GSP_BLINK_MASK 0x01）。
    - 经验补充：CMD_INFO failed 且设备枚举正常时，先"给车上电 / 拔插 DAPLink"再重试。
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2026-10-21 回退：撤销 1021-1318 那三件事，退回 1016-R182 的状态（他："回退上一版本"）
    本提交 = revert b788891（fw-1021-1318），逐项退回：
    1) GSP_CUT1/2/3_MM 883/1404/1906 → 683/1204/1706（切点里程 +200 退掉）
    2) GSP_ONEWAY_MASK 0x07 → 0x06（切点1 的"屏蔽右转"退掉，只留切点2/3）
    3) USE_BRANCH_EDGE 0 → 1（分支口接管开回来；gsp_dir_for()/k_gsp_dir[] 的 #if 一并撤回）
    没有丢东西：被退掉的那版在 tag `fw-1021-1318`（提交 b788891）上，
    hex 也已留档 firmware/1021-1318/test16.hex（SHA-256 adc07d42…8c10），
    要回来：git checkout fw-1021-1318，或直接烧那份 hex。
    校验：退回后 Code 应 =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
2026-10-21 重建 10-19 那版：切点里程 +100（783/1304/1806），其余 = 1016-R182
    他："再次回退，回退到今天我来改之前的版本" —— 选项里确认要的是「10-19 那次 +100 之后」。
    - GSP_CUT1/2/3_MM 683/1204/1706 → 783/1304/1806（只这三行数字，注释一律没动）
    - USE_BRANCH_EDGE 保持 1（接管开着）；GSP_ONEWAY_MASK 保持 0x06（切点1 不屏蔽右转）
    - 其余全部 = 1016-R182
    核对：git diff 5c85504 -- Core/ 只有那三行 #define 数字变化；Code=31916 与 R182 一致；0 Error 0 Warning
    留档：firmware/1021-1345/{test16.hex, SHA256SUMS, README.md}（README 里有三版对照表）
    ★10-19 那版当时没提交、也没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
2026-10-21 修正留档目录名：firmware/1021-1651 → 1021-1650（与 built 16:50 对齐）
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2026-10-22 IGC9：IG 判据亮>=4；KP 2.2（build 20:15:44；烧录待通——DAPLink CMD_INFO failed）
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

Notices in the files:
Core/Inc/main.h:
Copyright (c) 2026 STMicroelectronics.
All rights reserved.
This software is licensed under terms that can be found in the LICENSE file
